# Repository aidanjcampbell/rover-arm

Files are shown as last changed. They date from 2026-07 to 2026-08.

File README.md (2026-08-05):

# Rover-Arm — 4-DOF Rover-Mounted Robotic Arm



**A 3D-printed 4-DOF robotic arm lifting 1000 g at 30 cm reach, 200% of its 0.5 kg design target. 2x 12V DC Motors drive the rover while 4x Feetech servos power the arm, all controlled wirelessly by the ESP32. Designed, built, and tested from scratch.**
---

## Contents
- [Demo](#demo)
- [Overview](#overview)
- [Specifications](#specifications)
- [Key Engineering Decisions](#key-engineering-decisions)
- [Requirements & Verification](#requirements--verification)
- [Build Gallery](#build-gallery)
- [Bill of Materials](#bill-of-materials)
- [CAD & Firmware](#cad--firmware)
- [Development Timeline](#development-timeline)

---

## Demo

| | |
|---|---|
| <video src="https://github.com/user-attachments/assets/dd992043-898a-44c7-ab88-0e8c2c1f0734" width="600" controls></video> | **Payload test** — 1000 g held at 30 cm extension |
| <video src="https://github.com/user-attachments/assets/9e35d78c-9f56-43b6-9285-de8e3515913f" width="600" controls></video> | **Range of motion** — all 4 DOF |
| <video src="https://github.com/user-attachments/assets/c3312b9b-7194-4d76-a24a-d6187b4e6c03" width="600" controls></video> | **Control** — hold-to-jog from phone over onboard WiFi |

---

## Overview

I set out to design a mobile rover-mounted manipulator that lifts 0.5 kg at 30 cm extension, with every structural component printable on a consumer FDM machine. The arm has a 2-axis shoulder (pitch + yaw), single-axis elbow and wrist, and a fork-style end effector, all driven by Feetech serial bus servos on a single half-duplex TTL line.

All structural design, torque budgeting, and component selection are my own work. Firmware was developed with AI assistance (Claude) to move quickly through boilerplate code and debugging, keeping my focus on the mechanical design and system integration. I directed the architecture, integrated it with the hardware, and validated all behavior on the physical build.

---

## Specifications

| Parameter | Value |
|---|---|
| Design payload | 0.5 kg @ 30 cm extension |
| Demonstrated payload | 1.0 kg @ 30 cm |
| Reach | 30 cm |
| Actuators | ST3250 (50 kgf·cm) · 3× ST3215 (30 kgf·cm) |
|Drive Motors| 2x 12V DC 100RPM Motors |
| Controller | ESP32-WROOM-32 (Waveshare General Driver for Robots) |
| Control | Onboard WiFi AP + web UI, hold-to-jog |
| Power | 3S LiPo (11.1 V nominal) |
---

## Key Engineering Decisions

### Switching Control Architecture

Intending to build the entire rover off of the Arduino Uno R3 as my command module, I developed the entire base of the rover using this architecture until I realized that its limited pin numbers were going to cause problems when adding the servo bus. I then made the decision to start from scratch with the ESP32 General Robotics Driver.

Result: The General Robotics Driver integrated the TB6612FNG motor driver, wireless control, and the servo control all into one chip, giving us the number of pins we needed while simplifying electronics with a 47% reduction in internal wires (34 before, 18 after). Here is the full breakdown: [docs/wiringdiagrams.md](docs/wiringdiagrams.md)

### Servo Selection & Safety Factor
As I had no prior experience with robotic arms, I needed a way to break down the problem of servo selection into first principles. To do this, I calculated the torque required for the shoulder joint to lift the arm and a 0.5 KG payload with a safety factor of 2.64 to be 52.9 kg·cm. I also did these calculations for the other joints, which you can see alongside the actual math [here](docs/torquecalculations.md).

Result: I chose the ST3250 servo with 50kg·cm of torque for the shoulder joint. Though it was 5.5% under my calculated safety factor, I reasoned it to be the ideal choice (click the link above for details), and the payload tests affirmed this decision.

### Warren-Truss Forearm Link

The elbow-to-wrist link needed high bending stiffness at a very low mass to allow the actuators to lift the target payload. Rather than a solid printed beam, I used a Warren-truss geometry, which carries load through members in tension/compression rather than bending. The Fusion 360 model is parametric with member angles and lengths driven by expressions of the link length, so the truss regenerates correctly whenever the overall geometry changes without manual rework. See the render beside the integrated truss [here](#build-gallery).

### Base Stability Under Payload

Passing the payload test exposed the next constraint: at full extension, the combined center of gravity shifts forward of the front wheel contact line and the rover tips. Because this is a *mobile* platform, any counterweight added needs to be modular and fixed opposite the arm on the rotating base to offset the tip ping moment about the wheelbase.

Result: I developed and designed a modular counterweight system adaptable to any load the rover might undertake using readily available 2.5 lb. gym plates. The counterweight system scales by roughly 1 plate for every 500g added to the arm, allowing the rover to maintain mobility no matter the load. See more [here](docs/torquecalculations.md).

---

## Requirements & Verification

| # | Requirement | Design response | Verification |
|---|---|---|---|
| R1 | Lift 0.5 kg @ 30 cm | ST3250 shoulder + optimized truss designs + modular counterweight system | ✅ **Passed** — held 0.5 kg at full extension; demonstrated to 1.0 kg |
| R2 | Mobile rover base capable of supporting arm | Differential drive DC motors + custom ball bearing + counterweight | ✅ **Passed** — Rover stays stable while executing rapid maneuvers with an arm payload of 1000g (view the mobility test [here](media/1000g_mobility_test.mp4)) |
| R3 | Untethered operation | Onboard WiFi AP + 3S LiPo | ✅ **Passed** — operated for 20 minutes with arm under variable loads |
| R4 | Consumer-FDM printable | All parts fit P1S bed | ✅ Verified — print inventory in `/cad` |

---

## Build Gallery

<table>
  <tr>
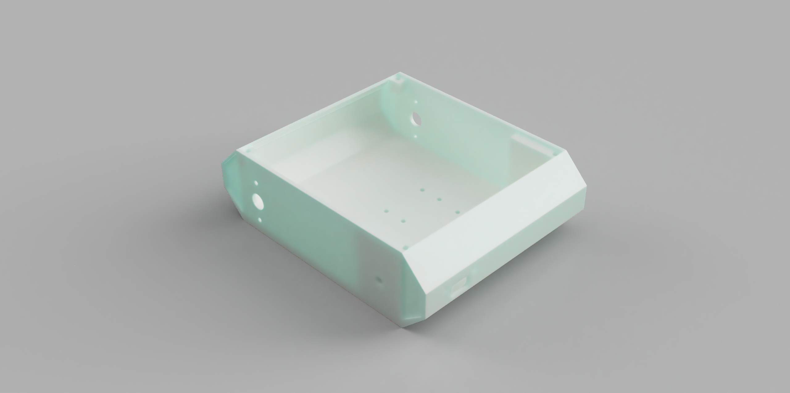
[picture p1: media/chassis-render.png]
    <td></td>
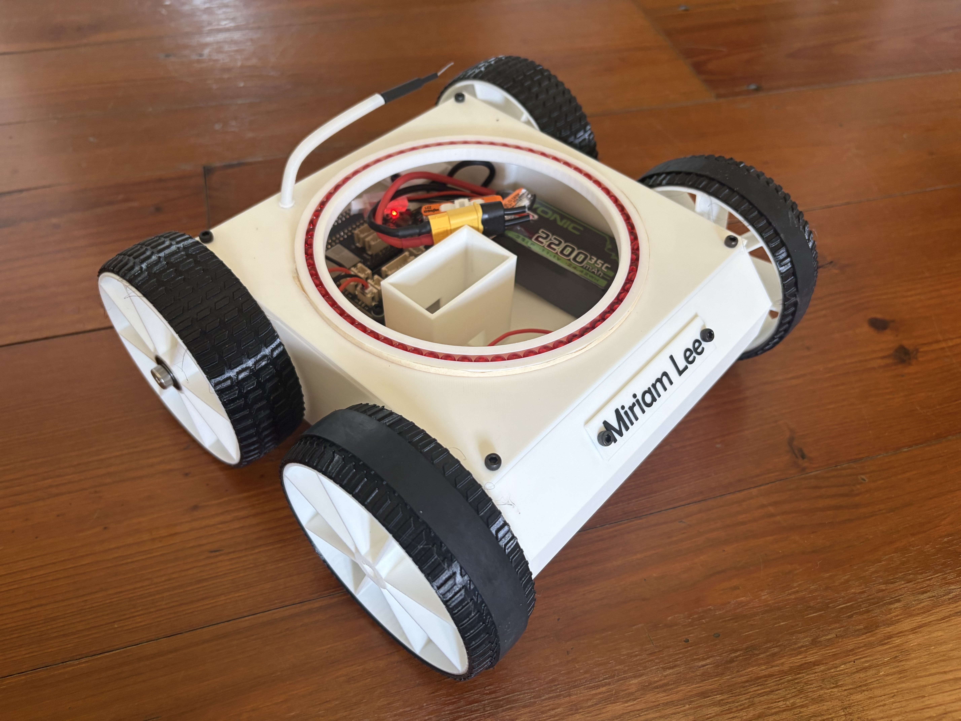
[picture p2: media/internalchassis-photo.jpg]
    <td></td>
  </tr>
  <tr>
    <td align="center"><em>Chassis render — CAD</em></td>
    <td align="center"><em>As built with internal electronics</em></td>
  </tr>
  <tr>
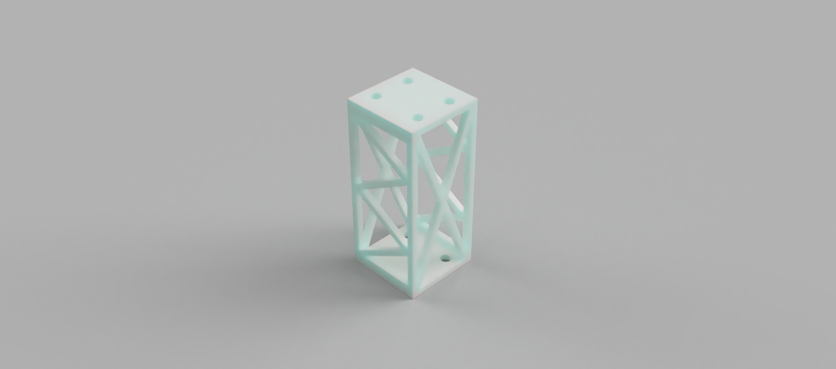
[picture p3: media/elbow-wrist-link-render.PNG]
    <td></td>
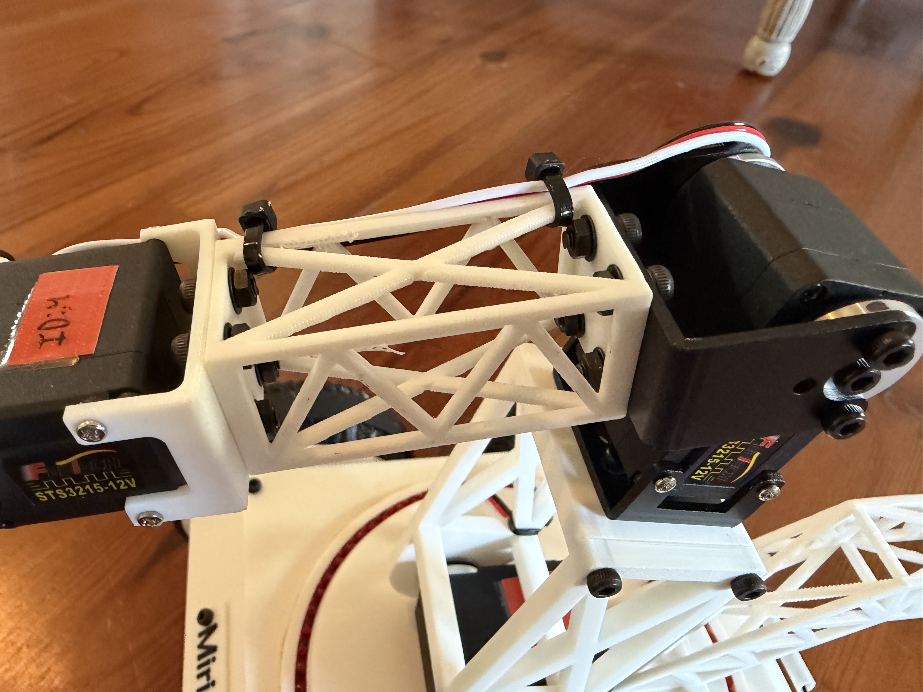
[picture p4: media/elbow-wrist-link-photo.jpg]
    <td></td>
  </tr>
  <tr>
    <td align="center"><em>Elbow-wrist link render — CAD</em></td>
    <td align="center"><em>As built integrated into arm </em></td>
  </tr>
  <tr>
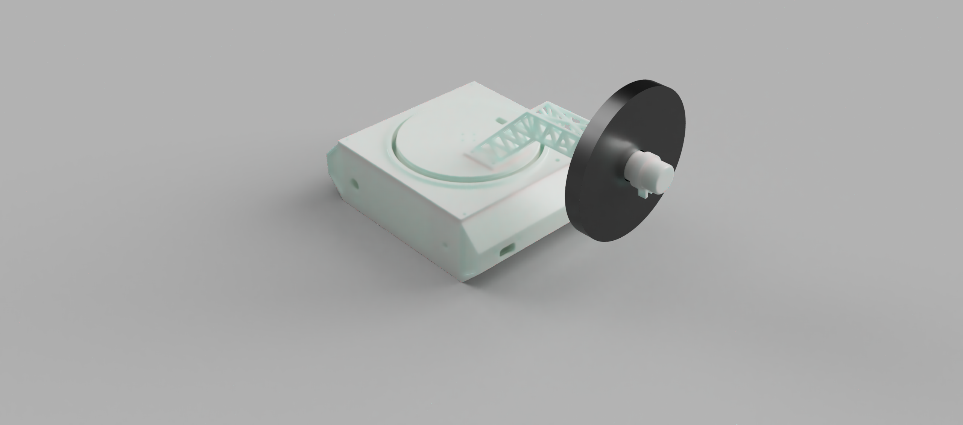
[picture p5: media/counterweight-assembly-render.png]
    <td></td>
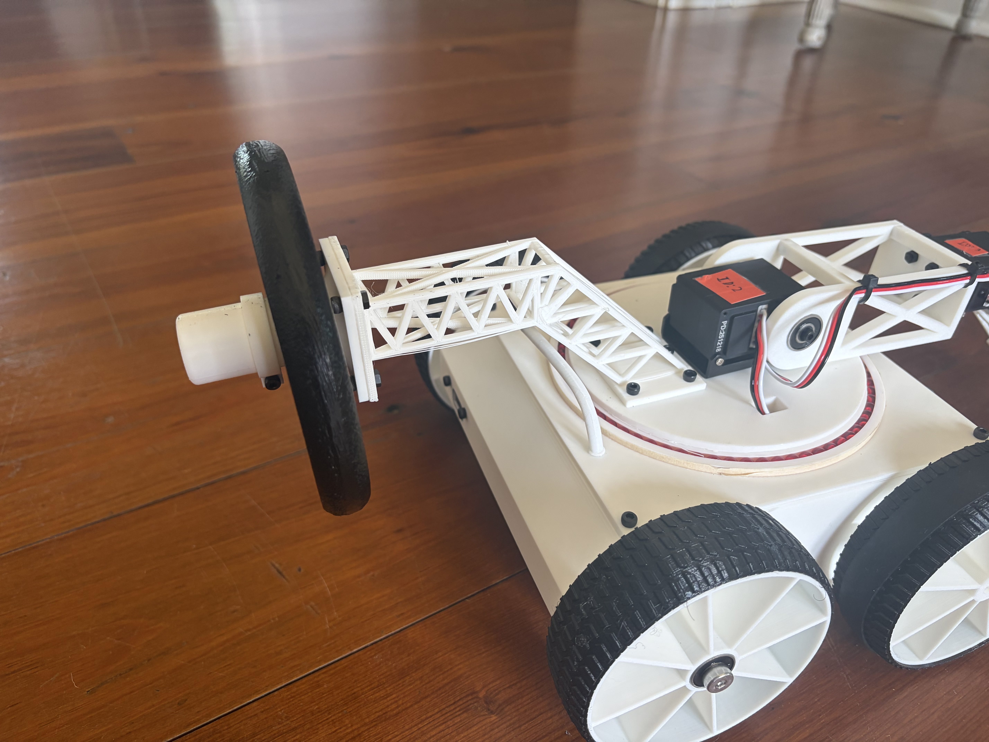
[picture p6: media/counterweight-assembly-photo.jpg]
    <td></td>
  </tr>
  <tr>
    <td align="center"><em>Counterweight assembly render— CAD</em></td>
    <td align="center"><em>As built with 2.5LB(1.1KG) plate </em></td>
  </tr>
  <tr>
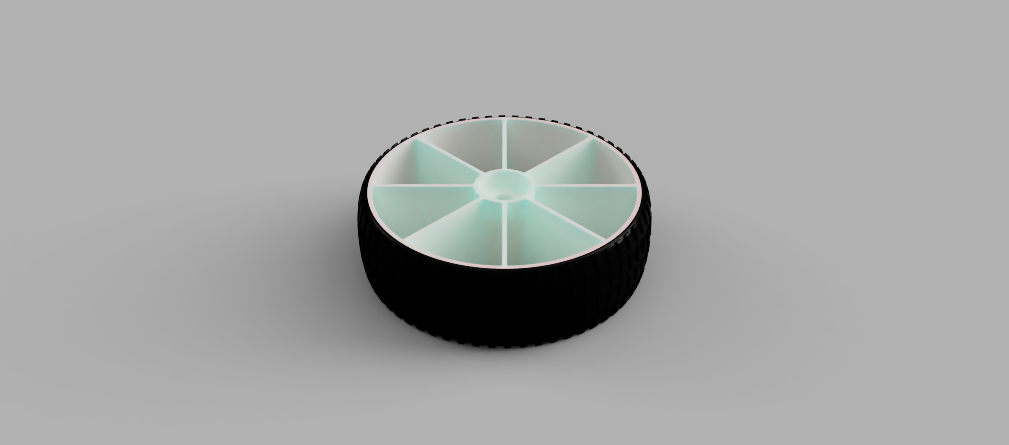
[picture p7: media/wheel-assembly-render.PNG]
    <td></td>
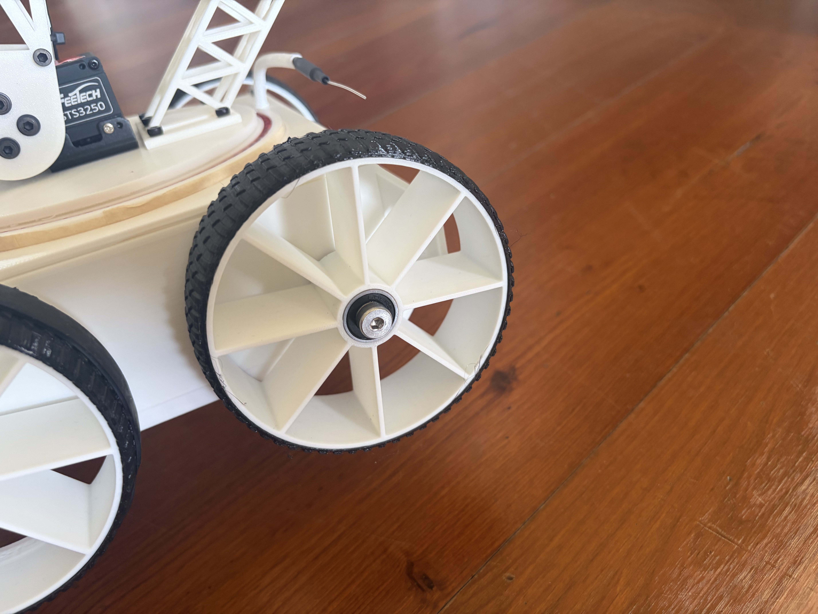
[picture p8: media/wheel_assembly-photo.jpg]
    <td></td>
  </tr>
  <tr>
    <td align="center"><em>Wheel assembly — CAD</em></td>
    <td align="center"><em>As built with non-drive wheel and TPU tire </em></td>
  </tr>
</table>

---

## Bill of Materials

*Key components below. [Full BOM — all hardware, quantities, costs (XLSX)](docs/BOM.xlsx)

| Component | Qty | Spec | Source | Price |
|---|---|---|---|---|
| Feetech ST3250 | 1 | 50 kgf·cm, 12V | [Babsco Supply](https://shop.babsco.com/feetech-sts3250-50kg-heavy-duty-smart-servo) | $64.99 |
| Feetech ST3215 | 3 | 30 kgf·cm, 12V | [DFRobot](https://www.dfrobot.com/product-2962.html) | $19.99 ea |
| Waveshare General Driver for Robots | 1 | ESP32 + TB6612FNG + Servo Bus Control| [Amazon](https://www.amazon.com/Multi-Functional-ESP32-WROOM-32-Bluetooth-Communications-Compatible/dp/B0BZLHYBJL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) | $27.99 |
| Ovonic 3S LiPo | 1 | 11.1V 2200 mAh XT60 | [Amazon](https://www.amazon.com/2200mAh-Connector-Airplane-Quadcopter-Helicopter/dp/B08CZF373Y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) | $16.99 |
| DC 12V 100RPM Motor | 2 | 100RPM 12V | [Amazon](https://www.amazon.com/Greartisan-Electric-Reduction-Centric-Diameter/dp/B072R57C56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) | $14.99 ea |

*Last verified: August 2026. Total: $330.15.*

---

## CAD & Firmware

**CAD** — [STEP files](cad/step/) (any CAD tool) · [STL files](cad/stl/) (print-ready; renders these in an interactive 3D viewer)

**Firmware** — PlatformIO (pioarduino ESP32 fork) + SCServo library. WiFi AP web server with hold-to-jog control, per-joint calibration arrays, build-timestamp version verification at boot.

```bash
pio run -t upload          # build & flash
# connect to "RoverArm" AP → http://192.168.4.1
```

Source and structure in [`/src`](src/).

---

## Development Timeline

- **Getting Started** - Prototyped rover base with intention to use Arduino Uno R3 & HC-05 Bluetooth module for wireless control
- **Architecture Swap** - Swapped Arduino for ESP32 General Robotics Driver after realizing pin limitations (see more [here](docs/wiringdiagrams.md))
- **Actuator sizing** - Torque & inertia calculations + safety-factor decomposition → ST3250 at shoulder pitch (see calculations [here](docs/torquecalculations.md)).
- **Servo bus bring-up** - Isolated a driver-board transceiver fault ([case study](docs/servo-issue.md)); first joint motion on replacement board.
- **Elbow-Wrist Linkage** - Designed/printed lightweight Warren-truss forearm to optimize strength within weight constraints
- **Payload test passed** - 0.5 kg at 30 cm (R1); demonstrated to 1.0 kg.
- **Base stability** — Diagnosed forward tipping resulting from heavy loads lifted by the arm and designed and printed a modular counterweight structure that could be variably loaded depending on arm load
- **Shoulder Joint Failure** - When lifting 1000g, the shoulder-elbow linkage deformed where it mounted to the shoulder servo and caused the arm to fail. Resolved by using a full bolt circle, revised design, and increasing the wall thickness and infill percent on the second iteration print. View the full breakdown [here](docs/structuralfailureanalysis.md).
- **1000g Payload Test** - Arm successfully lifted 1000g (200% of design target) and demonstrated mobile capability while under that load. Due to high heat in the shoulder servo body and several servo shutdowns after extended periods under load, testing will not progress with heavier weight to ensure the rover's continued function.
- **Elbow-Wrist Joint Failure** - During a public demonstration of the rover's capabilities the truss twisted under load and deformed, causing the arm to drop the payload. Resolved by adding two new crossmembers to further close both vertical faces of the truss and resist off-axis forces. View the full analysis [here](docs/structuralfailureanalysis.md).

---

## About

Mechanical engineering student, Georgia Tech. [email](mailto:aidanjcampbell1@gmail.com)

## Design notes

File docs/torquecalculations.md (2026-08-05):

# Torque Calculations — Robotic Arm

Torque sizing and actuator selection for the 4-DOF arm, worked from first principles.

## Requirement

Lift **0.5 kg** at **30 cm** maximum extension.

Configuration: 2-axis shoulder (pitch + yaw), single-axis elbow, single-axis wrist.

## Method
**Total Torque:**
```math
\tau_{\text{tot}} = \tau_s + \tau_I
```
**Static torque about a joint:**
```math
\tau_{\text{s}} = m \cdot L \cdot \cos\theta
```

For a multi-joint system, a joint carries the payload **and** every link and servo outboard of it, each at its own moment arm:

```math
\tau_{\text{joint}} = \sum m \cdot L \cdot \cos\theta
```
Torque is expressed in **kgf·cm**. Because kilogram-force already carries gravitational acceleration, using mass in kg and length in cm yields torque directly. Worst case is $\theta = 0$ (arm horizontal), where the moment arm is longest.

**Inertial Torque about a joint:**

```math
\tau_I = I \cdot \alpha
```
Where
```math
I = \sum mr^2
```
and
```math
\alpha = \frac{4\Delta \theta}{T^2}
```
Because inertia is calculated in $\text{kg}\cdot m^2$, we convert lengths to meters to start. Once we calculate inertial torque, we will convert it from $\text{N}\cdot\text{m}$ to $\text{kgf}\cdot\text{cm}$ using 10.2 $\text{kgf}\cdot\text{cm}$ =1 $\text{N}\cdot\text{m}$ to match our static torque calculations.

---

## Shoulder Pitch Torque

This joint carries the entire arm, so it will have the most torque and will likely be the limiting factor.
Masses are estimated as point masses and lengths as the distances from the center of mass to the shoulder pitch axis.

| Symbol | Quantity | Value |
|---|---|---|
| $m_p$ | Payload mass | 0.5 kg |
| $L_p$ | Payload moment arm| 30 cm |
| $m_{\text{se}}$ | Shoulder-elbow link mass | 0.05 kg |
| $L_{\text{se}}$ | Shoulder-elbow link moment arm| 7.5 cm |
| $m_{\text{es}}$ | Elbow servo mass | 0.055 kg |
| $L_{\text{es}}$ | Elbow servo moment arm | 13 cm |
| $m_{\text{ew}}$ | Elbow-wrist link mass | 0.04 kg |
| $L_{\text{ew}}$ | Elbow-wrist link moment arm | 20.5 cm |
| $m_{\text{ws}}$ | Wrist servo mass | 0.055 kg |
| $L_{\text{ws}}$ | Wrist servo moment arm| 26 cm |
| $m_{\text{f}}$ | Fork mass | 0.03 kg |
| $L_{\text{f}}$ | Fork moment arm| 28 cm |

**Static Torque**

Evaluated at $\theta = 0$, where the arm will experience the maximum load.
Payload contribution:

```math
\tau_p = m_p \cdot L_p \cdot \cos 0^\circ = 0.5 \times 30 \times 1 = 15\ \text{kgf·cm}
```

Link + servo contributions:

```math
\tau_{\text{unloaded arm}} = ((m_{\text{se}} \cdot L_{\text{se}}) + (m_{\text{es}} \cdot L_{\text{es}}) + (m_{\text{ew}} \cdot L_{\text{ew}}) + (m_{\text{ws}} \cdot L_{\text{ws}}) + (m_{\text{f}} \cdot L_{\text{f}})) \cdot \cos 0^\circ = \text{4.18}\ \text{kgf·cm}
```

Total static torque at the shoulder:

```math
\tau_{\text{shoulder}} = \tau_p + \tau_{\text{unloaded arm}} = 19.18 \text{kgf·cm}
```

**Inertial Torque**

Because the acceleration of the arm does not have a requirement, we will set the time to accelerate the arm $90^\circ$ or 1.57 rad to 2 seconds.
```math
\alpha = \frac{4(1.57)}{2^2} = 1.57 \text{rad/s}^2
```
We then calculate the inertia using the data table above.
```math
I = (m_{\text{se}} \cdot (L_{\text{se}})^2) + (m_{\text{es}} \cdot (L_{\text{es}})^2) + (m_{\text{ew}} \cdot (L_{\text{ew}})^2) + (m_{\text{ws}} \cdot (L_{\text{ws}})^2) + (m_{\text{f}} \cdot (L_{\text{f}})^2) + (m_p \cdot (L_p)^2)= 0.0538 \text{kg}\cdot\text{m}^2
```
Then we use the formula for total inertial torque
```math
\tau_I = I \cdot \alpha = (1.57)\text{rad/s}^2 \cdot (0.0538)\text{kg}\cdot\text{m}^2 = 0.08 \text{N}\cdot\text{m} 
```
Converting inertial torque from $\text{N}\cdot\text{m}$ to $\text{kg}\cdot\text{cm}$
```math
0.08 \text{N}\cdot\text{m} \cdot \frac{10.2 \text{kgf}\cdot\text{cm}}{1 \text{N}\cdot\text{m}} = 0.86 \text{kgf}\cdot\text{cm}
```
**Total Shoulder Torque**
```math
\tau_\text{tot} = \tau_s + \tau_I = 19.18 \text{kgf·cm} + 0.86 \text{kgf·cm} = 20.04 \text{kgf·cm}
```
### Safety Factor

| Factor | Value | Rationale |
|---|---|---|
| Continuous vs. stall | 2.0 | Rated stall torque is not usable continuous torque |
| Estimation error | 1.2 | Uncertainty in masses and arm lengths |
| Friction | 1.1 | Joint friction|
| **Stacked** | **≈ 2.64×** | product of the above |

**Required stall torque:**

```math
\tau_\text{req} =  20.04 \text{kgf·cm} \cdot 2.6 = 52.9 \text{kgf·cm}
```

### Selection

| Spec | Value |
|---|---|
| Required stall torque | 52.9 kgf·cm |
| Servo selected | ST3250 |
| Rated stall torque | 50 kgf·cm |
| Margin | 5.8% under |

The ST3250 is under our calculated safety factor, giving us a new safety margin of 2.50. This is a deliberate choice, as we included a large error margin in our estimation and friction safety factor calculations. This choice eats into that safety factor by 5.8%, which is an acceptable tolerance. If the margin below the calculated safety factor was larger, we would have to select another servo. The ST3250 is also the most powerful servo in the ST series, meaning that this is the most torque we can get without changing the architecture again.

---

## Other joints

### Elbow Torque

Because inertial torque is nominal at this joint and at the wrist joint, those calculations will be omitted as our estimation safety factor provides a significant margin for error.

| Symbol | Quantity | Value |
|---|---|---|
| $m_{\text{ew}}$ | Elbow-wrist link mass | 0.04 kg |
| $L_{\text{ew}}$ | Elbow-wrist link moment arm | 7.5 cm |
| $m_{\text{ws}}$ | Wrist servo mass | 0.055 kg |
| $L_{\text{ws}}$ | Wrist servo moment arm | 13 cm |
| $m_{\text{f}}$ | Fork mass | 0.03 kg |
| $L_{\text{f}}$ | Fork moment arm | 15 cm |
| $m_{\text{p}}$ | Payload  mass | 0.5 kg |
| $L_{\text{p}}$ | Payload  moment arm | 17 cm |

```math
\tau_{\text{elbow}} = \sum m \cdot L \cdot \cos 0^\circ = \text{9.9}\ \text{kgf·cm}
```

Required stall torque (× 2.64): **26.14 kgf·cm** → **ST3215** selected, rated 30 kgf·cm.

---

### Wrist Torque

| Symbol | Quantity | Value |
|---|---|---|
| $m_{\text{f}}$ | Fork mass | 0.03 kg |
| $L_{\text{f}}$ | Fork moment arm| 2 cm |
| $m_{\text{p}}$ | Payload mass | 0.5 kg |
| $L_{\text{f}}$ | Payload moment arm | 4 cm |

```math
\tau_{\text{wrist}} = \sum m \cdot L \cdot \cos 0^\circ = \text{2.06}\ \text{kgf·cm}
```

Required stall torque (× 2.6): **5.44 kgf·cm** → **ST3215** selected, rated 30 kgf·cm.

---
## Counterweight torque

The counterweight supplies the **restoring moment** that opposes the arm's tipping moment about the front tipping line. Because it is mounted on the shoulder opposite the arm, it swings through the same arc, so its moment arm is the horizontal distance from the tipping line to the plate's center of mass. Because the tipping line at the front wheels is the most prone to tipping, we will calculate the torque from this point.

Plate spec: one 2.5 lb steel plate = **1.134 kg**.

| Symbol | Quantity | Value |
|---|---|---|
| $m_{cw}$ | Counterweight mass (1 plate) | 1.134 kg |
| $d_{cw}$ | Moment arm (tipping line → CW center of mass) | 23 cm |

### Single plate — 0.5 kg payload

```math
\tau_{cw} = m_{cw} \cdot d_{cw} = 1.134 \times 23 = 26.082\ \text{kgf·cm}
```

This 26.082 kgf·cm is the restoring torque the counterweight directly provides, sizing the arm to lift a 0.5 kg (500 g) payload at full extension. Combined with the chassis restoring moment, it yields the full stability margin recorded below.

### Two plates — 1.0 kg payload

Doubling the payload to 1.0 kg (1000 g) doubles the tipping moment the counterweight must offset. Since the 23 cm moment arm is fixed, the counterweight torque scales linearly with plate mass, so the plate count doubles. Two 2.5 lb plates give 2.267 kg:

```math
\tau_{cw} = m_{cw} \cdot d_{cw} = 2.267 \times 23 = 52.141\ \text{kgf·cm}
```

### Payload-to-counterweight scaling

| Payload | Counterweight | CW mass | Moment arm | Counterweight torque |
|---|---|---|---|---|
| 0.5 kg (500 g) | 1 × 2.5 lb plate | 1.134 kg | 23 cm | 26.082 kgf·cm |
| 1.0 kg (1000 g) | 2 × 2.5 lb plates | 2.267 kg | 23 cm | 52.141 kgf·cm |

With the moment arm held constant at 23 cm, each 2.5 lb plate contributes a fixed **26.082 kgf·cm** of restoring torque. The counterweight requirement therefore scales roughly one plate per 500 g of payload, which makes the modular system an easily extended sizing rule rather than a one-off value.

### Stability check: does the counterweight actually keep the rover upright?

Counterweight torque alone isn't the full picture — it has to be checked against everything trying to tip the rover forward: the arm's own structural weight plus the payload.

| Term | Value |
|---|---|
| $\tau_{arm}$ (arm structure) | 2.784 kgf·cm |
| $\tau_{payload}$ (0.5 kg payload) | 12.000 kgf·cm |
| **$\tau_{tip}$ (total tipping)** | **14.784 kgf·cm** |
| $\tau_{chassis}$ (chassis restoring) | 7.7722 kgf·cm |
| $\tau_{cw}$ (counterweight, 1 plate) | 26.082 kgf·cm |
| **$\tau_{restore}$ (total restoring)** | **33.854 kgf·cm** |

```math
SF = \frac{\tau_{restore}}{\tau_{tip}} = \frac{33.854}{14.784} = 2.29\times
```

Restoring torque exceeds tipping torque by **2.29×** at full extension (θ = 0), the worst-case pose — the rover is stable with meaningful margin, not just barely balanced. And because the system is scalable, we can add another 2.5 lb. plate for every 500g added to the arm load to maintain roughly the same safety factor.

### Dynamic loading margin

The stability check above assumes the arm is stationary. In motion — accelerating a joint or stopping suddenly at a limit — inertial forces briefly add to the tipping side on top of the static gravitational torque. A rigorous treatment would sum $i \alpha r^2$ across every link mass using a measured angular acceleration, but without that hardware data, I used a conservative padding factor instead.

A **1.5× dynamic multiplier** is applied to the static tipping torque to bound worst-case deceleration (e.g. a hard limit-switch stop):

```math
\tau_{tip,dynamic} = 1.5 \times \tau_{tip,static} = 1.5 \times 14.784 = 22.176\ \text{kgf·cm}
```

Checking this against the existing restoring torque:

```math
SF_{dynamic} = \frac{\tau_{restore}}{\tau_{tip,dynamic}} = \frac{33.854}{22.176} = 1.53\times
```

The single-plate counterweight still restores the rover with margin under a padded worst-case dynamic load, though the margin compresses from 2.29× to 1.53× once motion is accounted for.

**Limitations.** The 1.5× factor is an assumed conservative bound, not a measured value as it was not derived from servo acceleration data. A more precise figure would require measuring joint angular acceleration (α) during a commanded move or hard stop, e.g. via high-speed video, and computing $\tau_{dyn} = \sum m \alpha r^2$ across the arm's link masses. However, the counterweight has proven to be effective as seen in this mobility test video with the 1000g payload:
<video src="https://github.com/user-attachments/assets/91ab42fd-473b-42c3-9ab9-9755cc8a7e65" width="800" controls></video>

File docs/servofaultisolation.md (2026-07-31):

# Servo Fault Isolation

## The symptom

I installed a new controller board and wired it to the arm. On power-up, the board's status light came on, but the connected servo would not respond to any command. No movement. No error message. No partial or intermittent behavior. Complete silence.

## Why silence is the hard case

Most bugs give you a thread to pull. A wrong number, an error message, a behavior that's *almost* right. Leads like these allow you to focus in on a specific hardware piece or section of code. But in this situation, I had nothing to initially focus my attention to.

To work around this, I decided to look at the broad picture of the interactions taking place that would make this servo eventually move. By dividing everything into systems, first hardware/software and then further, I was able to isolate areas of possible failure and test them independently.
## The initial signal

While the servo was not functioning, there was a status light visible inside the servo housing. This led me to believe that the servo was at least receiving power and possibly commands, focusing my attention towards software first.

## Mapping the possibilities

Before touching anything, I listed every layer that could produce total silence:

- my control software
- the communication settings (servo ID, wiring orientation, device addresses)
- the physical wiring
- a defective motor
- a defect on the board itself

Here is my full problem diagnosis tree:

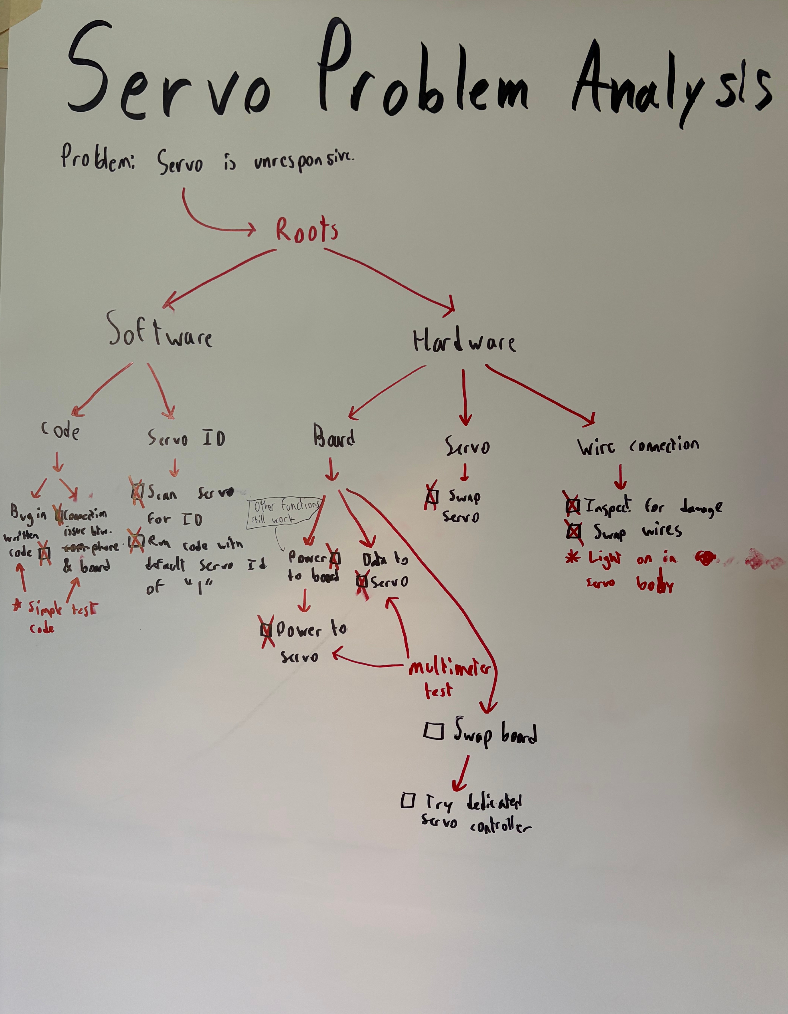
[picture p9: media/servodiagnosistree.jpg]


To efficiently work through this tree and eliminate as many potential problems as possible while following the hint the status light gave me, I decided to start on the software side of the tree. In doing this, I was able to eliminate any potential software bugs before I tried replacing hardware, which delays iteration speed with shipping time and costs more money. 

## Shrinking the problem

The full firmware ran a web interface, motor control, and a wireless connection layered on top of the motor communication. Any of those could have been interfering. So I set all of it aside and wrote a bare test program that did nothing but talk to the motors.

This was the core move: hold everything constant, remove one thing. If the motors worked in the stripped-down program, the fault lived somewhere in the rest of the system. If they still didn't, I'd eliminated an entire category of suspects in a single step.

With that minimal test I confirmed, one check at a time: the board had power, the software was the correct version, the wiring matched the manufacturer's own reference exactly, every valid orientation of the communication wires was tried, and I scanned the full range of possible servo IDs at every possible communication speed. Each check closed off a branch. None produced a response.

## The remaining three

That left three possibilities I could not tell apart from software:

1. a defective motor
2. a defect on the board
3. a defective wire

These three were physically separable, and I could state in advance what each test would prove:

- **Another servo on the same board.** If it works, the first servo was the problem. If it doesn't, the servo isn't the issue.
- **Another wire with the same setup.** If it works, the first wire was the problem. If it doesn't, that leaves only the board on my decision tree.
- **The same setup on a second board.** If it works, the original board was defective. If it doesn't, the fault is somewhere I haven't looked yet or with the design of the board itself, testable with a bare-bones servo controller.

Stating the expected outcome *before* running the test is what separates a diagnosis from swapping parts and hoping something changes.

## Resolution

I first used a multimeter to test if the board was supplying sufficient power to the servo and if the data line was working, both of which were. As all other functions on the board seemed to work properly, I decided to move on to test the other two possibilities.

But after testing both the new servo and new wire (the servo and wire to be used on the elbow joint), they both produced no result, eliminating them from the tree.

I then moved the identical code and hardware setup onto a replacement board. The motors responded immediately.

Nothing in my software, wiring, or configuration had changed — so the one thing that *did* change was the fault. The original board had a defective communication circuit: either a factory defect or a component I damaged during the development process, either of which would have gone unnoticed as all other functions worked.

## Why the diagnosis mattered

The fix was trivial: swap a board. That's worth being honest about — the value here was never the fix.

The days went into *earning* the conclusion. A hardware defect is the one root cause that can't be measured directly; no test ever reads "board faulty." It can only be reached by eliminating everything under my control first. Blaming the hardware before that point is a guess; blaming it after is a diagnosis. The discipline was refusing the comfortable assumption that the new part was fine until I had concretely proven where the fault was not.

## Principles

1. When a system is completely silent, there's no signal to follow — shrink the space instead: hold everything constant, remove one variable at a time, until the cause is cornered.
2. A hardware fault is only a credible conclusion after the controllable parts are exhausted, never before. Reaching for it early feels like progress and usually isn't.

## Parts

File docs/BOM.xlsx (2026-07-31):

Bill of Materials
Rover Project | Aidan Campbell |  |  | 2026-07-17
Item | Quantity | Unit Price($) | Total Price($) | Source | Purchase Link | Notes
Feetech ST3215 12V | 3 | $19.99 | $59.97 | DFRobot | DFRobot ST3215 (https://www.dfrobot.com/product-2962.html)
Feetech ST3250 12V | 1 | $64.99 | $64.99 | Babsco | Babsco ST3250 (https://shop.babsco.com/feetech-sts3250-50kg-heavy-duty-smart-servo)
ST32 Series Servo Horns | 4 | N/A | N/A | N/A | N/A | Included with servo purchases
ST32 Series Servo Bushings | 2 | N/A | N/A | N/A | N/A | Included with servo purchases
ST32 Series Screws | 12 | N/A | N/A | N/A | N/A | Included with servo purchases
ST32 Series Servo Wires | 4 | N/A | N/A | N/A | N/A | Included with servo purchases
Waveshare General Robotics Driver | 1 | $27.99 | $27.99 | Amazon | Waveshare Board (https://www.amazon.com/Multi-Functional-ESP32-WROOM-32-Bluetooth-Communications-Compatible/dp/B0BZLHYBJL)
M3 15mm Standoffs | 4 | N/A | $5.69 | Amazon | Lagogia M3 Standoffs (https://www.amazon.com/Female-Standoff-Quadcopter-Computer-Circuit/dp/B0BPCKHLT5)
12V DC Motor 100RPM | 2 | $14.99 | $29.98 | Amazon | 12V DC Motor (https://www.amazon.com/Greartisan-Electric-Reduction-Centric-Diameter/dp/B072R57C56)
11.1V 2200 mAh LiPo Battery | 1 | $16.99 | $16.99 | Amazon | Ovonic 11.1V LiPo (https://www.amazon.com/2200mAh-Connector-Airplane-Quadcopter-Helicopter/dp/B08CZF373Y)
XT60 Female Connector | 1 | N/A | $4.89 | Amazon | Ledavillage XT60 (https://www.amazon.com/Ledvillage-Female-Connector-Battery-Included/dp/B0DB1V6FFY)
22 AWG Assorted Stranded Wires | 1 | N/A | $9.00 | Amazon | Fermerry wire kit (https://www.amazon.com/Fermerry-Stranded-Electric-Tinned-Copper/dp/B089CQ2N69)
22 AWG x 2.8mm Female Spade Connector | 4 | N/A | $5.99 | Amazon | Baomian Connector Kit (https://www.amazon.com/Baomain-Insulated-Connector-Electrical-Terminal/dp/B01962MW2G)
Heat Shrink Tubing 2.5x45 mm | 10 | N/A | $4.99 | Amazon | Rindion Heat Shrink (https://www.amazon.com/Rindion-127PCS-Heat-Shrink-Tubing/dp/B0DYSV5Z9B) | Any diameter 2-3mm and length 20-50mm could substitute
M5 30mm Shoulder Screw | 2 | N/A | $7.99 | Amazon | UXCell M5 Screws (https://www.amazon.com/uxcell-Stainless-Socket-Shoulder-Length/dp/B077GYB893)
606-2RS 6x17x6mm Ball Bearing | 5 | N/A | $6.49 | Amazon | UXCell 606-2RS
2.5 x 200mm Zip Ties | 4 | N/A | $3.99 | Amazon | HoAoOo Cable Ties (https://www.amazon.com/Nylon-Cable-inches-Heavy-2-5mm/dp/B0GR52PRHF)
JST-PH 2.0 Connector | 2 | N/A | $5.99 | Amazon | Twisina JST PH (https://www.amazon.com/Connector-Connectors-Female-Silicone-Cables/dp/B0GWYR7CQ2)
JST-XH 2.54 Connector | 1 | N/A | $6.99 | Amazon | ZSDZFYLLK JST-XH (https://www.amazon.com/JST-XH-2-54mm-Connector-Silicone-Cables/dp/B0D6KSMK1Q)
M3x6mm socket cap screws | 31 | N/A | $9.99 | Amazon | Fgruh M3 Kit (https://www.amazon.com/Fgruh-750PCS-Assortment-Washers-Assorted/dp/B0FGV5FCBN) | M3 750 piece kit. Only 1 required for all M3 screws needed.
M3x8mm socket cap screws | 27 | N/A |  | Amazon | Fgruh M3 Kit (https://www.amazon.com/Fgruh-750PCS-Assortment-Washers-Assorted/dp/B0FGV5FCBN) | Included in Fgruh M3 Kit
M3x12mm socket cap screws | 1 | N/A |  | Amazon | Fgruh M3 Kit | Included in Fgruh M3 Kit
M3x16mm socket cap screws | 4 | N/A |  | Amazon | Fgruh M3 Kit | Included in Fgruh M3 Kit
M3 Nut | 25 | N/A |  | Amazon | Fgruh M3 Kit | Included in Fgruh M3 Kit
M5x8mm Heat-Set Insert | 2 | N/A | $8.99 | Amazon | FFVRVSS Heat Inserts (https://www.amazon.com/M2-M2-5-M3-Threaded-Inserts/dp/B0FH4JQ3VB) | 320+6pcs M2-M5 set. Only 1 required for all heat set inserts.
M3x5mm Insert | 23 | N/A |  | Amazon | FFVRVSS Heat Inserts (https://www.amazon.com/M2-M2-5-M3-Threaded-Inserts/dp/B0FH4JQ3VB) | Included in FFVRVSS Heat Insert Kit
PLA Filament 1.75mm white | ~1kg | $15.29 | $15.29 | Amazon | SUNLU PLA Filament (https://www.amazon.com/Printer-Filament-SUNLU-Dimensional-Accuracy/dp/B07ZNHF46J)
90a TPU Filament 1.75mm black | 240g | $24.99 | $24.99 | Amazon | SUNLU TPU Filament (https://www.amazon.com/SUNLU-TPU-Filament-1-75mm-Flexible/dp/B0FB95ZMCM)
Size #85 Rubber Bands | 2 | N/A | $8.96 | Amazon | HAIDIBAO Rubber Bands (https://www.amazon.com/HAIDIBAO-Rubber-Assorted-Elastic-Survival-Tactical/dp/B0DNFGJYNZ) | For enhanced tire grip if TPU lacks traction on slick surfaces
 |  | Total Price: | $330.15

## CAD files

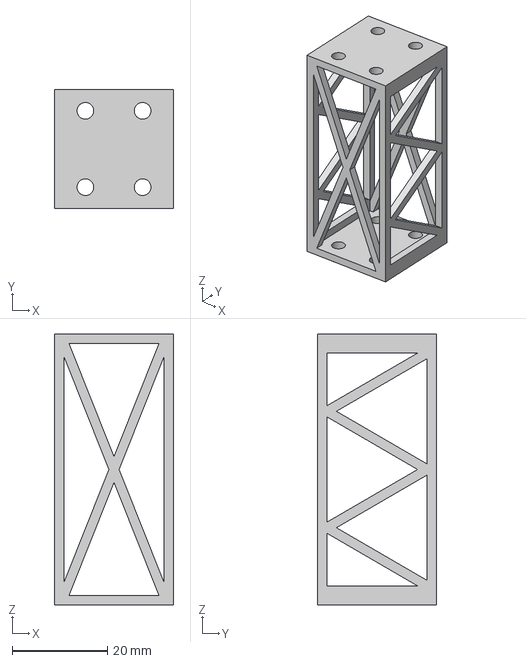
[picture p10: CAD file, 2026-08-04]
cad/step/elbow-wrist-link.step
25.0 x 25.0 x 56.8 mm

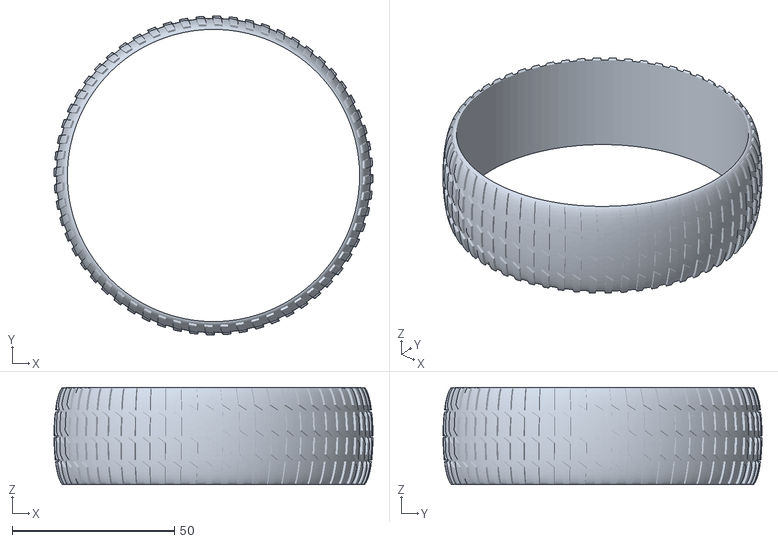
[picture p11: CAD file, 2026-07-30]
cad/stl/tire.stl
98.2 x 98.2 x 30.0

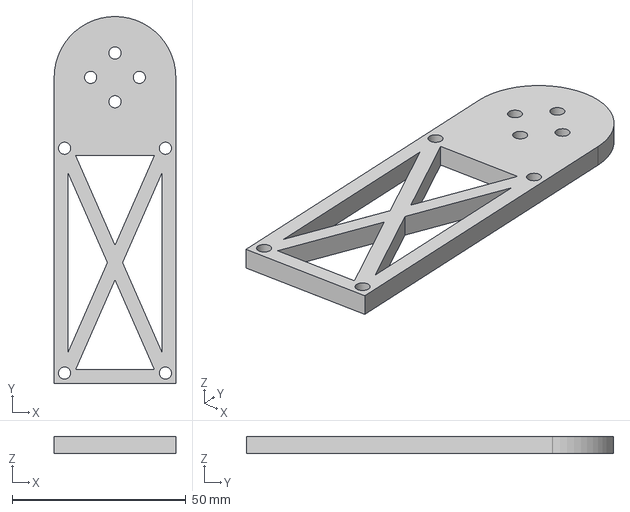
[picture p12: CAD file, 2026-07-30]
cad/step/shoulder-elbow-servo-link.step
35.0 x 105.5 x 5.00 mm

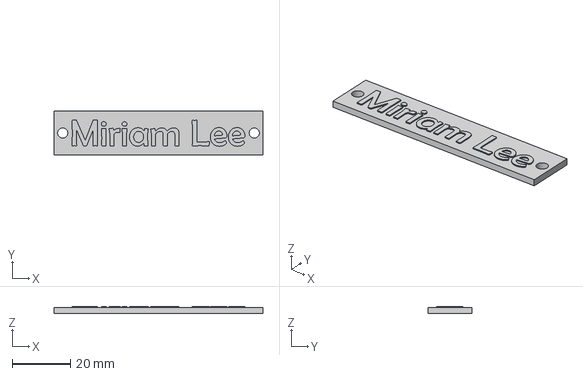
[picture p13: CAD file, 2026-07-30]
cad/step/nameplate.step
72.0 x 15.0 x 2.32 mm

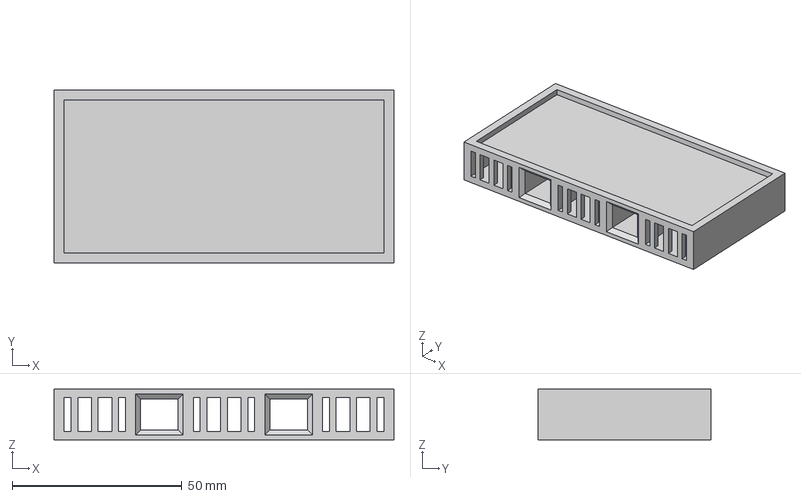
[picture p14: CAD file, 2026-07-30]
cad/step/pallet.step
100.0 x 51.0 x 15.0 mm

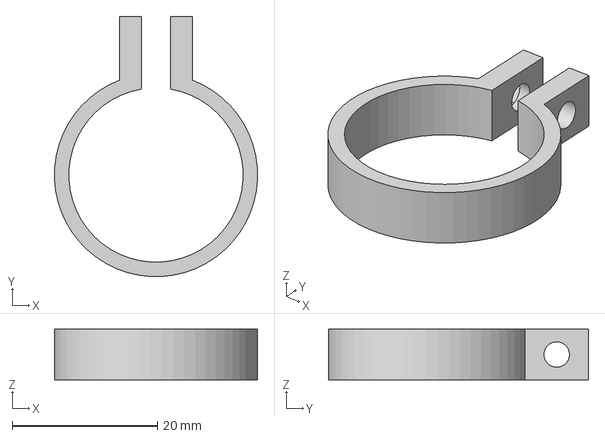
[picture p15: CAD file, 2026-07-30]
cad/step/counterweight-clamp.step
28.0 x 35.8 x 7.00 mm

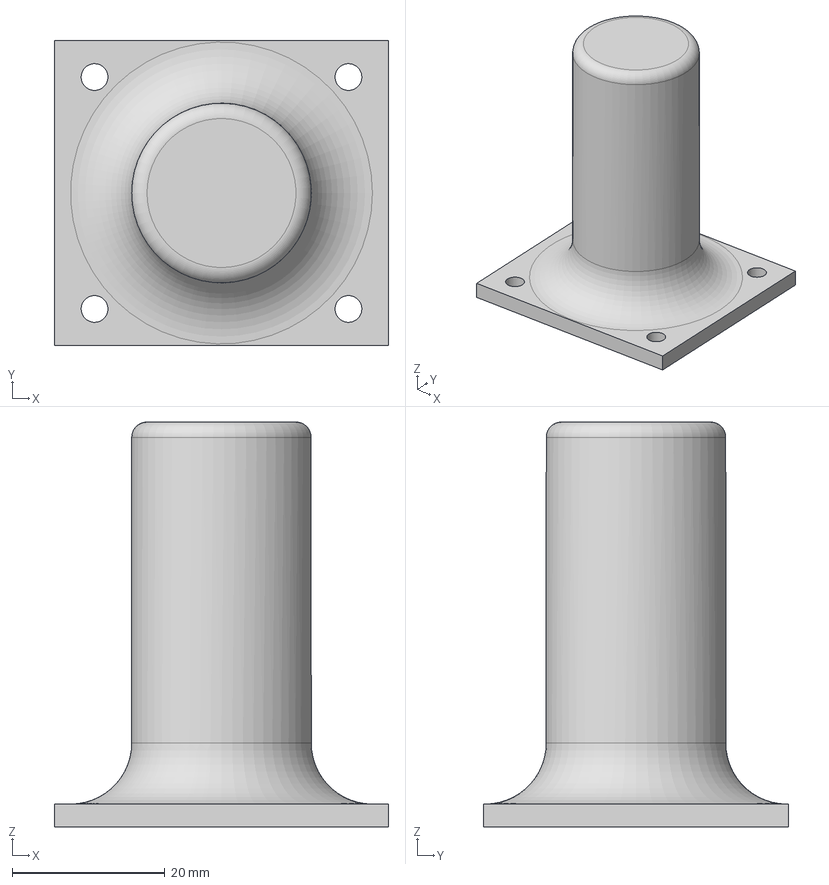
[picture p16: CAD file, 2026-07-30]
cad/step/counterweight-holder.step
43.8 x 40.0 x 53.0 mm

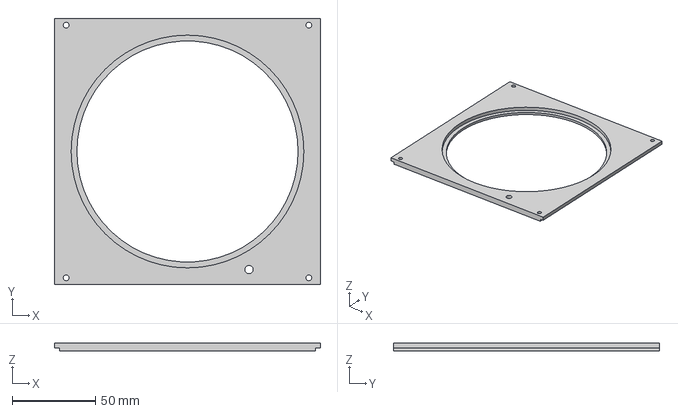
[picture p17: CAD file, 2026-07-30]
cad/step/top-plate.step
160.0 x 160.0 x 5.00 mm

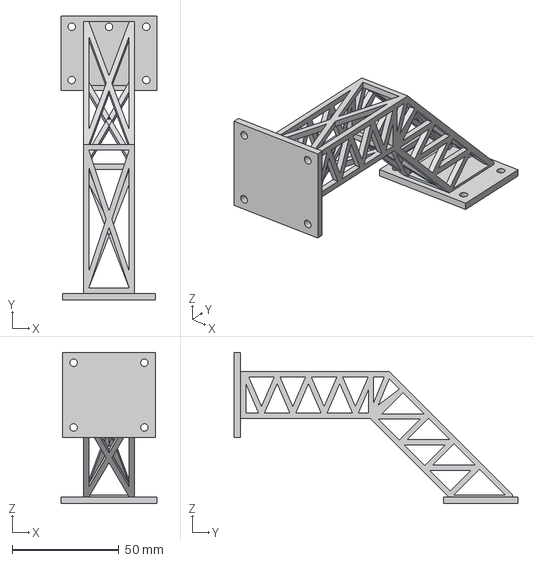
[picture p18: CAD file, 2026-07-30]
cad/step/counterweight-truss.step
45.0 x 133.1 x 70.8 mm

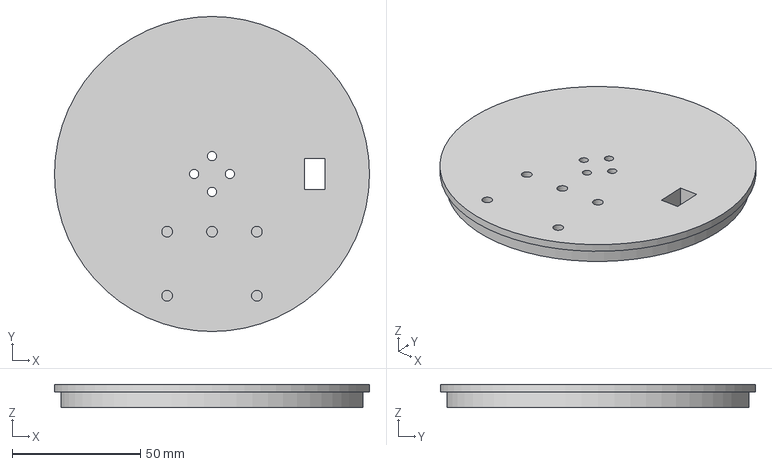
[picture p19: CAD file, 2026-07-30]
cad/step/yaw-plate.step
122.9 x 122.9 x 9.00 mm

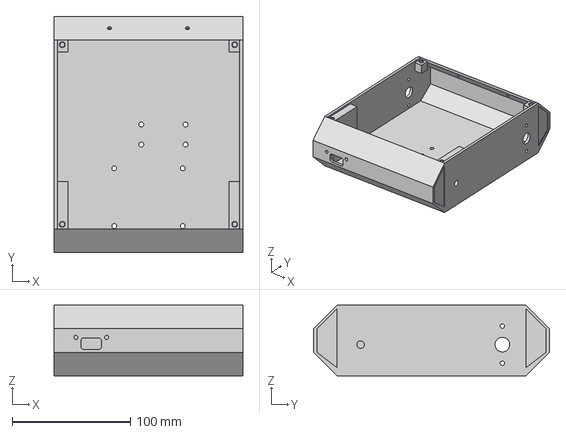
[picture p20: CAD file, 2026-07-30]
cad/step/chassis.step
160.0 x 200.0 x 60.0 mm

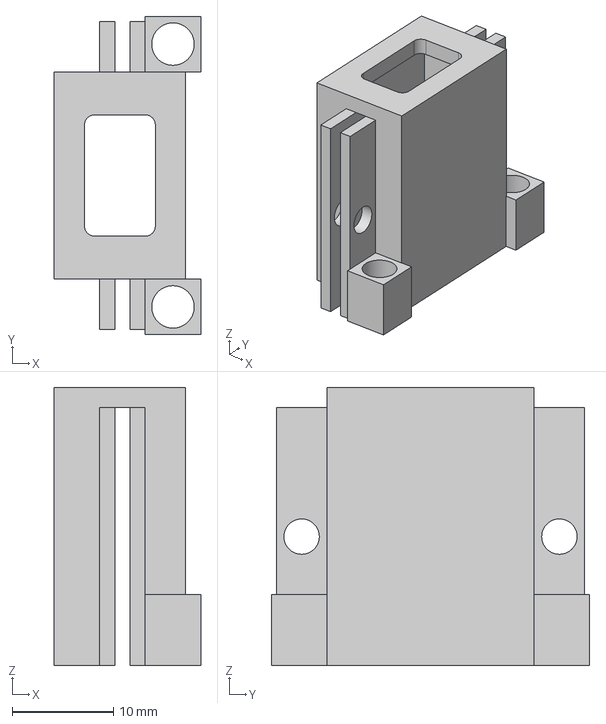
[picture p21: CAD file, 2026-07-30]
cad/step/USB-holder.step
14.5 x 31.5 x 27.5 mm

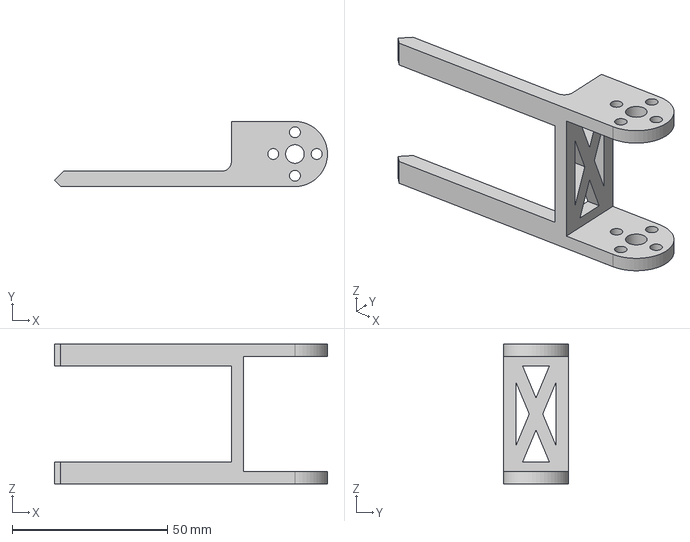
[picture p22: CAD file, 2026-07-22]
cad/step/fork-end-effector.step
88.0 x 21.0 x 45.0 mm

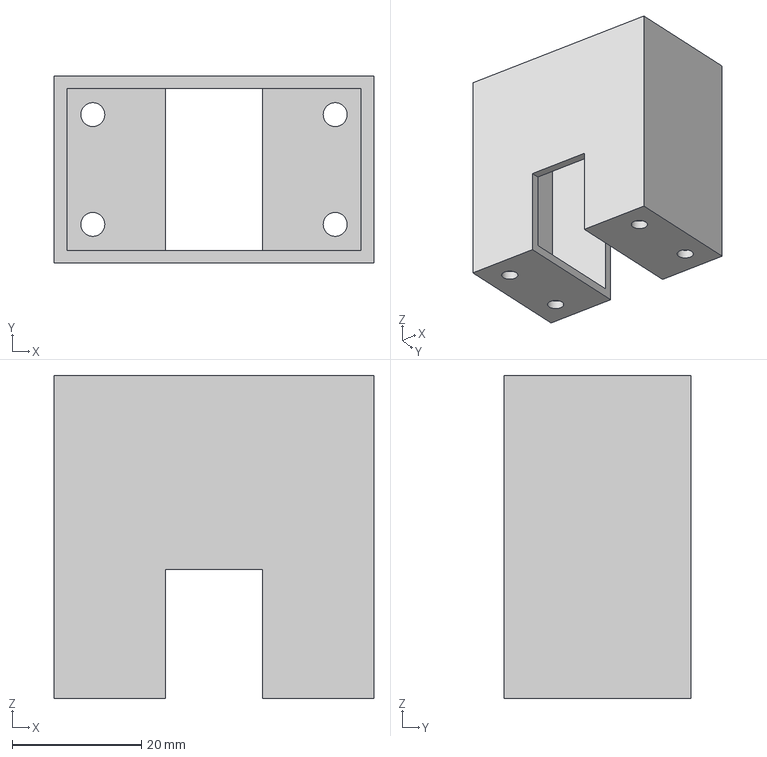
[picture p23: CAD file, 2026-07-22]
cad/step/servo-box.step
49.5 x 29.0 x 50.0 mm

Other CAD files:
cad/step/shoulder-bearing-spacer.step
cad/step/servo-bracket.step
cad/step/antenna-structure.step
cad/step/non-drive-wheel.step
cad/step/drive-wheel.step
cad/step/shoulder-elbow-link.step
cad/step/shoulder-yaw-bearing.step
cad/step/wheel-spacer.step
cad/stl/USB-holder.stl
cad/stl/antenna-structure.stl
cad/stl/chassis.stl
cad/stl/counterweight-clamp.stl
cad/stl/counterweight-holder.stl
cad/stl/counterweight-truss.stl
cad/stl/drive-wheel.stl
cad/stl/elbow-wrist-link.stl
cad/stl/fork-end-effector.stl
cad/stl/nameplate.stl
cad/stl/non-drive-wheel.stl
cad/stl/pallet.stl
cad/stl/servo-box.stl
cad/stl/servo-bracket.stl
cad/stl/shoulder-bearing-spacer.stl
cad/stl/shoulder-elbow-link.stl
cad/stl/shoulder-elbow-servo-link.stl
cad/stl/shoulder-yaw-bearing.stl
cad/stl/top-plate.stl
cad/stl/wheel-spacer.stl
cad/stl/yaw-plate.stl

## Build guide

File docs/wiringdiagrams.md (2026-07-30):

# Wiring & Control Architecture
 
The control electronics were migrated from an initial **Arduino Uno** prototype to the **Waveshare General Driver for Robots 
(ESP32-WROOM-32)**. This document shows both wiring architectures and explains the reasoning behind the switch.

## Why the architecture changed

The Uno prototype hit a hard limit with pin space, a crucial component for the platform.
The decisive factor was the **serial bus servos**: the Feetech actuators run on a half-duplex serial bus at 1,000,000 baud, 
which needs a *dedicated* hardware UART. The Uno has a single UART shared with USB programming/debug, 
so the servo bus and the debug link contend for the same peripheral, meaning a dedicated servo controller wpould have to be added into the architecture. Add in the motor driver and HC-05 Bluetooth module along with the dedicated servo controller, and the Arduino does not have enough pins to support that architecture, not to mention its complexity.

| Requirement | Arduino Uno | Waveshare (ESP32) |
|---|---|---|
| Serial bus servos @ 1 Mbaud | Single UART, shared with USB — no dedicated bus | Multiple hardware UARTs; dedicated `Serial1` on GPIO18/19 |
| Wireless control | None, requires HC-05 bluetooth module | Onboard Wi-Fi; hosts the `RoverArm` AP + web UI at 192.168.4.1 |
| Motor driving | Requires separate motor driver | Integrated TB6612FNG driver |

The switch consolidated the electronics onto a single robotics-purpose board and freed a dedicated UART for the servo bus, which later proved important when diagnosing a servo bus power issue (see [`servofaultisolation.md`](servofaultisolation.md)).

## Diagram 1 — Original architecture (Arduino Uno)

Original wiring: Arduino Uno prototype architecture

The initial prototype: This setup worked well in the beginning as I was familiar with using the Arduino Uno R3, but quickly reached its limits once I needed to add the servo bus and control.

## Diagram 2 — Current architecture (Waveshare ESP32)

Current wiring: Waveshare General Driver (ESP32) architecture

The current system: power distribution from the 3S LiPo, the ESP32 hosting the Wi-Fi AP and web interface, the integrated TB6612FNG driving the drive motors, and the Feetech servo bus running on `Serial1` (GPIO18 `S_RXD` / GPIO19 `S_TXD`), half-duplex at 1,000,000 baud.

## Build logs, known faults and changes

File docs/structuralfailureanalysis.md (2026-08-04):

# Structural Failure Analysis: Shoulder Joint and Forearm Truss at 1000g
 
While testing the rover at a 1000g payload — 200% of its 0.5 kg design target — I encountered two separate structural failures on the arm. This is a record of both: what failed, why it failed, and what I changed to fix the root cause.
 
The two are worth reading together because they failed for different reasons. The first was a build failure--the design was sound, but I did not assemble the part correctly. The second was a design failure--the part was built as intended, but my model of how it would be loaded was incomplete. One taught me to build and assemble to spec; the other taught me to question my load assumptions.
 
---
 
## Failure #1: Shoulder–Elbow Joint
 
<video src="https://github.com/user-attachments/assets/7db130d6-03f4-4d7d-aa30-b8c59f9642bd" width="600" controls></video>
*The joint giving way during the first 1000g payload test.*
 
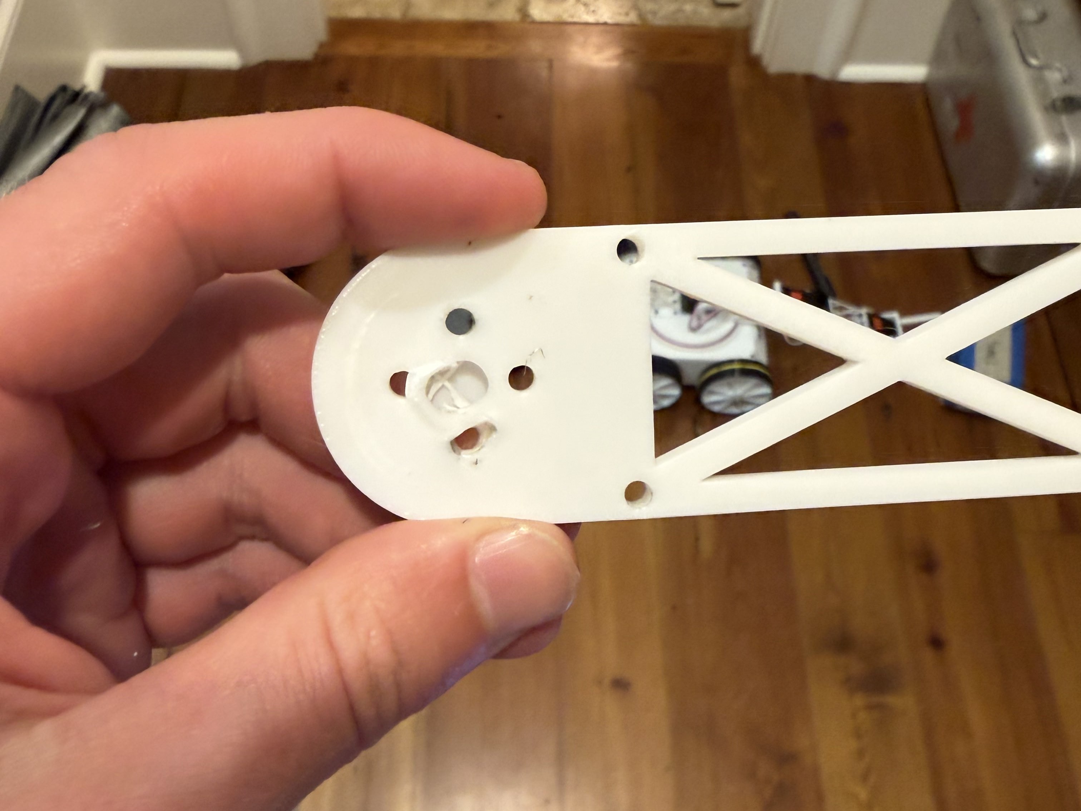
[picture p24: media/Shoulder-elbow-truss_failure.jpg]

*The mounting plate after failure with the deformed screw holes.*
 
This failure appeared the first time I tested the 1000 g payload. The mounting plate on the shoulder–elbow link — the plate that bolts to the shoulder servo horn and carries the entire arm — deformed and pulled apart at the screw holes under the accumulated stress of repeated payload tests.
 
**Root causes:**
 
- **Prototype print settings.** The link holding up the whole arm had been printed at 2 walls and 15% infill — settings that are fine for prototyping but not for carrying large loads. With too few perimeters around the screw bosses, the holes had little material to resist the load and began to deform and elongate until they tore through.
- **Too few fasteners.** I had used two fasteners at the joint instead of the four the design called for, because two allowed faster disassembly during iteration. That forced the entire arm load through two screws, which was inadequate under heavy payload.
- **Hand-drilled center hole.** The center hole that lets the plate sit flush on the servo horn had been drilled with a power tool after printing rather than modeled into the part. This left a weak spot at the center of the plate and disrupted the surrounding material, which contributed to the screw holes deforming and failing.

**Fixes, each addressing a specific cause:**
 
- **Print settings → 3 walls, 25% infill.** The extra perimeters put more solid material around the screw bosses, where the load actually transfers, giving the holes far more resistance to deformation.
- **Fasteners → four, with washers and preload.** Going back to the full four-fastener pattern with washers spreads the load across the joint instead of concentrating it on two screws. I also preloaded the bolts more firmly: clamping the plate against the servo horn lets the joint carry load through friction across the whole mating face, taking stress off the screw holes themselves rather than relying on the screws in shear alone.
- **Center hole → designed into the print.** Modeling the hole into the part kept the surrounding material continuous and the plate's structural integrity intact.
**Result:** These changes fixed the joint. The reprinted link has passed several further 1000g tests without deformation.
 
---
 
## Failure #2: Elbow–Wrist Forearm Truss

*The single-crossmember truss after it twisted under an off-axis load.*
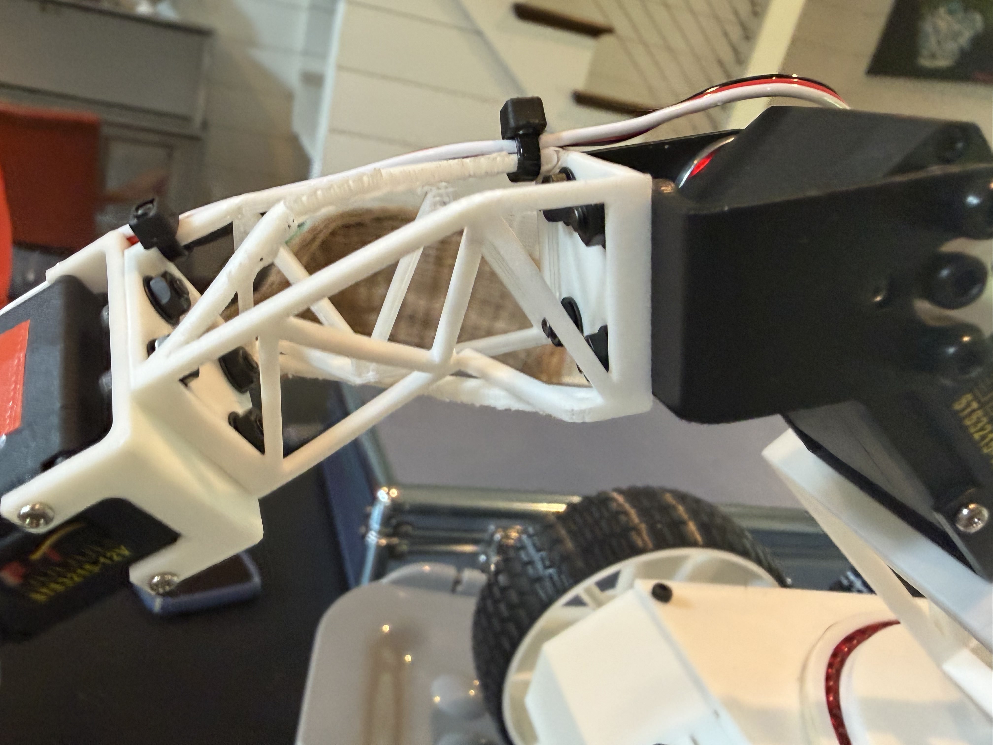
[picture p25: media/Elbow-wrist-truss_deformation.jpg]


This failure appeared during a demonstration of the rover lifting 1000 g. Mid-lift, the elbow–wrist link twisted along its length and deformed, and the arm failed.
 
**Root cause:**
 
I had designed the elbow–wrist link to be highly weight-optimized — strong where it needed to be, light everywhere else. Working from that mindset, I gave the top and bottom faces of the truss only a single crossmember each, because I expected the link to carry load only vertically, down the side faces. That reasoning held for a purely vertical load. But when the rover lifts a payload that isn't perfectly balanced, or when the arm accelerates in the yaw direction, the load comes off the vertical axis and tries to twist the link along its length. With only one crossmember per face, the top and bottom behaved as an **open section**, which has very little torsional stiffness — so under that off-axis load, the truss twisted rather than holding its shape.
 
**Fix:**
 
<!-- MEDIA: render or photo of the two-crossmember redesign -->

 
I redesigned the truss with the same weight-optimization mindset but a corrected understanding of how it would actually be loaded. The change was to run **two crossmembers per face instead of one**. Tying the top and bottom faces together this way further closes the section, better approximating a true closed section. This design resists torsion far better than a fully open one while keeping the lightweight advantage of a truss over a solid beam. The realization behind the fix wasn't "add more material"; it was that I had modeled only the in-plane bending load and missed the torsional load path.
 
**Result:** the redesigned truss has passed every 1000g test since, and it holds its shape far better when the arm is loaded during dynamic movement.
 
---
 
## Takeaway
 
Both failures resulted from deliberately testing past the design requirement to reveal the real limits of the build. The shoulder joint failed because the as-built part drifted from its design under the pressure of rapid iteration; the fix was discipline in fabrication. The forearm truss failed because the design itself was built on an incomplete load model; the fix was a better understanding of the loads. Together they moved the arm from meeting its 0.5 kg target to holding 1000g repeatably.

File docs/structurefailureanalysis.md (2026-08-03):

# Structural Failure Analysis: Shoulder Joint and Forearm Truss at 1000 g
 
While testing the rover at a 1000 g payload — 200% of its 0.5 kg design target — I encountered two separate structural failures that took the arm out of service. This is a record of both: what failed, why it failed, and what I changed to fix the root cause.
 
The two are worth reading together because they failed for different reasons. The first was a build failure — the design was sound, but the as-built part didn't match it. The second was a design failure — the part was built as intended, but my model of how it would be loaded was incomplete. One taught me to build to spec; the other taught me to question my load assumptions.
 
---
 
## Failure #1: Shoulder–Elbow Joint
 
<!-- MEDIA: failure video — drag-and-drop the 1000 g joint-failure clip here on GitHub, or replace the line below -->
Shoulder–elbow joint failing during the first 1000 g test
*The joint giving way during the first 1000 g payload test.*
 
<!-- MEDIA: photo of the deformed part -->
Deformed shoulder–elbow mounting plate
*The mounting plate after failure — the screw holes deformed and tore out under load.*
 
This failure appeared the first time I tested the 1000 g payload. The mounting plate on the shoulder–elbow link — the plate that bolts to the shoulder servo horn and carries the entire arm — deformed and pulled apart at the screw holes under the accumulated stress of repeated payload tests.
 
**Root causes:**
 
- **Prototype print settings.** The link holding up the whole arm had been printed at 2 walls and 15% infill — settings that are fine for prototyping but not for carrying large loads. With too few perimeters around the screw bosses, the holes had little material to resist the load and began to deform and elongate until they tore through.
- **Too few fasteners.** I had used two fasteners at the joint instead of the four the design called for, because two allowed faster disassembly during iteration. That forced the entire arm load through two screws, which was inadequate under heavy payload.
- **Hand-drilled center hole.** The center hole that lets the plate sit flush on the servo horn had been drilled with a power tool after printing rather than modeled into the part. This left a weak spot at the center of the plate and disrupted the surrounding material, which contributed to the screw holes deforming and failing.

**Fixes, each addressing a specific cause:**
 
- **Print settings → 3 walls, 25% infill.** The extra perimeters put more solid material around the screw bosses, where the load actually transfers, giving the holes far more resistance to deformation.
- **Fasteners → four, with washers and preload.** Going back to the full four-fastener pattern with washers spreads the load across the joint instead of concentrating it on two screws. I also preloaded the bolts more firmly: clamping the plate against the servo horn lets the joint carry load through friction across the whole mating face, taking stress off the screw holes themselves rather than relying on the screws in shear alone.
- **Center hole → designed into the print.** Modeling the hole into the part kept the surrounding material continuous and the plate's structural integrity intact.
**Result:** these changes fixed the joint. The reprinted link has passed several further 1000 g tests without deformation.
 
---
 
## Failure #2: Elbow–Wrist Forearm Truss
 
<!-- MEDIA: photo of the twisted/deformed truss -->
Twisted elbow–wrist forearm truss
*The single-crossmember truss after it twisted under an off-axis load.*
 
This failure appeared during a demonstration of the rover lifting 1000 g. Mid-lift, the elbow–wrist link twisted along its length and deformed, and the arm failed.
 
**Root cause:**
 
I had designed the elbow–wrist link to be highly weight-optimized — strong where it needed to be, light everywhere else. Working from that mindset, I gave the top and bottom faces of the truss only a single crossmember each, because I expected the link to carry load only vertically, down the side faces. That reasoning held for a purely vertical load. But when the rover lifts a payload that isn't perfectly balanced, or when the arm accelerates in yaw, the load comes off the vertical axis and tries to twist the link along its length. With only one crossmember per face, the top and bottom behaved as an **open section**, which has very little torsional stiffness — so under that off-axis load, the truss twisted rather than holding its shape.
 
**Fix:**
 
<!-- MEDIA: render or photo of the two-crossmember redesign -->
Redesigned two-crossmember truss
*The redesign — a second crossmember on each face closes the section toward a box.*
 
I redesigned the truss with the same weight-optimization mindset but a corrected understanding of how it would actually be loaded. The change was to run **two crossmembers per face instead of one**. Tying the top and bottom faces together this way closes the section further — better approximating a true closed section, which resists torsion far better than an open one — while keeping the lightweight advantage of a truss over a solid beam. The realization behind the fix wasn't "add more material"; it was that I had modeled only the in-plane bending load and missed the torsional load path entirely.
 
**Result:** the redesigned truss has passed every 1000 g test since, and it holds its shape far better when the arm is loaded during dynamic movement.
 
---
 
## Takeaway
 
Both failures came from deliberately testing past the design requirement, which is what that testing is for — it found the real limits of the build. The shoulder joint failed because the as-built part drifted from its design under the pressure of rapid iteration; the fix was discipline in fabrication. The forearm truss failed because the design itself was built on an incomplete load model; the fix was a better understanding of the loads. Together they moved the arm from meeting its 0.5 kg target to holding 1000 g repeatably.

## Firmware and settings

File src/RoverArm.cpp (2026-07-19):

#include <Arduino.h>
#include <WiFi.h>
#include <WebServer.h>
#include <SCServo.h>

//Motor A pins
#define PWMA 25
#define AIN1 21
#define AIN2 17

//Motor B pins
#define PWMB 26
#define BIN1 22
#define BIN2 23

#define SERVO_TX 19
#define SERVO_RX 18

#define ID_SHOULDER_PITCH 2
#define ID_SHOULDER_YAW 1
#define ID_ELBOW 3
#define ID_WRIST 4

//--------Jog control------------
#define JOG_STEP 25 //position units added/removed per nudge
#define JOG_SPEED 800 //speed at which the jog moves


//Wifi Access point credentials
const char* apSSID = "RoverArm";
const char* apPassword = "rover1234";

WebServer server(80);
SMS_STS servos;

int jointPos[5];
int jointCenter [5];
int jointMin[5];
int jointMax[5];


//==================================
//Motor Control
//==================================
void setMotorA(int speed) {
  //speed: -255 (full reverse) to 255 (full forward)
  if (speed > 0) {
    digitalWrite(AIN1, HIGH);
    digitalWrite(AIN2, LOW);
  }else if (speed < 0) {
    digitalWrite(AIN1, LOW);
    digitalWrite(AIN2, HIGH);
  }else {
    digitalWrite(AIN1, LOW);
    digitalWrite(AIN2, LOW);
  }
  analogWrite(PWMA, abs(speed));  //abs() strips the negative
}

void setMotorB(int speed) {
  if (speed > 0) {
    digitalWrite(BIN1, HIGH);
    digitalWrite(BIN2, LOW);
  }else if (speed < 0) {
    digitalWrite(BIN1, LOW);
    digitalWrite(BIN2, HIGH);
  }else {
    digitalWrite(BIN1, LOW);
    digitalWrite(BIN2, LOW);
  }
  analogWrite(PWMB, abs(speed));
}
//This is to prevent the ESP Board browning out from high current draw from the motors, which causes the WiFi to go out
void rampMotors(int targetA, int targetB) {
  int currentA = 0;
  int currentB = 0;
  while (currentA != targetA || currentB != targetB) {
    if (currentA < targetA) currentA = min(currentA + 15, targetA);
    if (currentA > targetA) currentA = max(currentA - 15, targetA);
    if (currentB < targetB) currentB = min(currentB + 15, targetB);
    if (currentB > targetB) currentB = max(currentB - 15, targetB);
    setMotorA(currentA);
    setMotorB(currentB);
    delay(10);
  }
}
//==================================
//Sevo Control
//Feetech Position Units: 0-4095 = 0-360 degrees (~ 11.375 steps/degree)
//speed units: 0-32767 (higher->faster, 1500 is safe moderate)
//==================================
void moveServo(byte id, int pos, int spd) {
  servos.WritePosEx(id, pos, spd, 50);
  //end # = acceleration
}

void centerServo(byte id) {
  jointPos[id] = jointCenter[id];
  moveServo(id, jointCenter[id], 1500);
}

//nudges a joint one JOG_STEP further in the given direction
//constrained by position max/min
//-1 = up/left
//+1 = down/right
void nudgeJoint(byte id, int direction) {
  int newPos = jointPos[id] +(direction*JOG_STEP);
  newPos = constrain(newPos, jointMin[id], jointMax[id]);
  jointPos[id]=newPos;
  moveServo(id, newPos, JOG_SPEED);
}

const char* htmlPage = R"HTMLEND(
<!DOCTYPE html>
<html>
<head>
  <title>Rover Control</title>
  <meta name="viewport" content="width=device-width, initial-scale=1">
  <style>
    body {
      text-align: center;
      font-family: sans-serif;
      max-width: 400px;
      margin: auto;
      padding: 10px;
    }
    h2 { margin: 10px 0 5px 0; }
    hr { margin: 15px 0; }
    .btn {
      font-size: 18px;
      padding: 14px;
      margin: 4px;
      width: 100px;
      border: none;
      border-radius: 8px;
      background: #007AFF;
      color: white;
      cursor: pointer;
      user-select: none;
      -webkit-user-select: none;
      touch-action: manipulation;
    }
    .btn:active { background: #005BBB; }
    .stop { background: #FF3B30; width: 220px; }
    .stop:active { background: #CC2A22; }
    #status {
      font-size: 13px;
      color: gray;
      margin-top: 8px;
      height: 18px;
    }
  </style>
</head>
<body>
 
  <h1>Rover Control</h1>
  <div id="status">Ready</div>
 
  <h2>Drive</h2>
  <p><button class="btn" onclick="cmd('/forward')">Forward</button></p>
  <p>
    <button class="btn" onclick="cmd('/left')">Left</button>
    <button class="btn" onclick="cmd('/right')">Right</button>
  </p>
  <p><button class="btn" onclick="cmd('/backward')">Backward</button></p>
  <p><button class="btn stop" onclick="cmd('/stop')">STOP</button></p>
 
  <hr>
  <h2>Arm</h2>
  <p><button class="btn" onclick="cmd('/arm/center')">Center All</button></p>
 
  <h2>Shoulder Pitch</h2>
  <p>
    <button class="btn"
      onmousedown="startJog('/servo/shoulder_pitch/nudge_up', event)"
      onmouseup="stopJog()" onmouseleave="stopJog()"
      ontouchstart="startJog('/servo/shoulder_pitch/nudge_up', event)"
      ontouchend="stopJog()" ontouchcancel="stopJog()">Up</button>
    <button class="btn" onclick="cmd('/servo/shoulder_pitch/center')">Center</button>
    <button class="btn"
      onmousedown="startJog('/servo/shoulder_pitch/nudge_down', event)"
      onmouseup="stopJog()" onmouseleave="stopJog()"
      ontouchstart="startJog('/servo/shoulder_pitch/nudge_down', event)"
      ontouchend="stopJog()" ontouchcancel="stopJog()">Down</button>
  </p>
 
  <h2>Shoulder Yaw</h2>
  <p>
    <button class="btn"
      onmousedown="startJog('/servo/shoulder_yaw/nudge_left', event)"
      onmouseup="stopJog()" onmouseleave="stopJog()"
      ontouchstart="startJog('/servo/shoulder_yaw/nudge_left', event)"
      ontouchend="stopJog()" ontouchcancel="stopJog()">Left</button>
    <button class="btn" onclick="cmd('/servo/shoulder_yaw/center')">Center</button>
    <button class="btn"
      onmousedown="startJog('/servo/shoulder_yaw/nudge_right', event)"
      onmouseup="stopJog()" onmouseleave="stopJog()"
      ontouchstart="startJog('/servo/shoulder_yaw/nudge_right', event)"
      ontouchend="stopJog()" ontouchcancel="stopJog()">Right</button>
  </p>
 
  <h2>Elbow</h2>
  <p>
    <button class="btn"
      onmousedown="startJog('/servo/elbow/nudge_up', event)"
      onmouseup="stopJog()" onmouseleave="stopJog()"
      ontouchstart="startJog('/servo/elbow/nudge_up', event)"
      ontouchend="stopJog()" ontouchcancel="stopJog()">Up</button>
    <button class="btn" onclick="cmd('/servo/elbow/center')">Center</button>
    <button class="btn"
      onmousedown="startJog('/servo/elbow/nudge_down', event)"
      onmouseup="stopJog()" onmouseleave="stopJog()"
      ontouchstart="startJog('/servo/elbow/nudge_down', event)"
      ontouchend="stopJog()" ontouchcancel="stopJog()">Down</button>
  </p>
 
  <h2>Wrist</h2>
  <p>
    <button class="btn"
      onmousedown="startJog('/servo/wrist/nudge_up', event)"
      onmouseup="stopJog()" onmouseleave="stopJog()"
      ontouchstart="startJog('/servo/wrist/nudge_up', event)"
      ontouchend="stopJog()" ontouchcancel="stopJog()">Up</button>
    <button class="btn" onclick="cmd('/servo/wrist/center')">Center</button>
    <button class="btn"
      onmousedown="startJog('/servo/wrist/nudge_down', event)"
      onmouseup="stopJog()" onmouseleave="stopJog()"
      ontouchstart="startJog('/servo/wrist/nudge_down', event)"
      ontouchend="stopJog()" ontouchcancel="stopJog()">Down</button>
  </p>
 
  <script>
    function cmd(route) {
      var s = document.getElementById("status");
      s.textContent = "Sending...";
      var xhr = new XMLHttpRequest();
      xhr.open("GET", route, true);
      xhr.onload = function() {
        if (xhr.status === 200) {
          s.textContent = "OK";
        } else {
          s.textContent = "Error " + xhr.status;
        }
      };
      xhr.onerror = function() {
        s.textContent = "No response";
      };
      xhr.send();
    }
 
    // ── Hold-to-jog control ─────────────────────────────────
    // While a jog button is held, fire cmd(route) repeatedly.
    // On release, stop firing -- the servo simply stays at its
    // last commanded position (no separate "stop" needed).
    let jogInterval = null;
 
    function startJog(route, evt) {
      if (evt) evt.preventDefault(); // stop touch from also firing a synthetic mousedown
      if (jogInterval) return;       // already jogging, ignore repeat triggers
      cmd(route);                    // immediate first move so it feels responsive
      jogInterval = setInterval(function() { cmd(route); }, 20);
    }
 
    function stopJog() {
      if (jogInterval) {
        clearInterval(jogInterval);
        jogInterval = null;
      }
    }
  </script>
 
</body>
</html>
)HTMLEND";

void handleRoot() {
  server.send(200, "text/html", htmlPage);
}

void handleForward()  { rampMotors(150, 150);    server.send(200, "text/plain", "OK"); }
void handleBackward() { rampMotors(-150, -150);  server.send(200, "text/plain", "OK"); }
void handleLeft()     { rampMotors(-150, 150);   server.send(200, "text/plain", "OK"); }
void handleRight()    { rampMotors(150, -150);   server.send(200, "text/plain", "OK"); }
//void handleStop()     { rampMotors(0, 0);        server.send(200, "text/plain", "OK"); }
void handleStop() {
  setMotorA(0);
  setMotorB(0);
  server.send(200, "text/html", htmlPage);
}
void handleArmCenter() {
  centerServo(ID_SHOULDER_PITCH);
  centerServo(ID_SHOULDER_YAW);
  centerServo(ID_ELBOW);
  centerServo(ID_WRIST);
  server.send(200, "text/plain", "OK");
}

// ── Shoulder pitch ─────────────────────────────────────────────
void handleShoulderPitchNudgeUp()     { nudgeJoint(ID_SHOULDER_PITCH, +1); server.send(200, "text/plain", "OK"); }
void handleShoulderPitchNudgeDown()   { nudgeJoint(ID_SHOULDER_PITCH, -1); server.send(200, "text/plain", "OK"); }
void handleShoulderPitchCenter()   { centerServo(ID_SHOULDER_PITCH); server.send(200, "text/plain", "OK"); }

// ── Shoulder yaw ───────────────────────────────────────────────
void handleShoulderYawNudgeLeft()     { nudgeJoint(ID_SHOULDER_YAW, +1); server.send(200, "text/plain", "OK"); }
void handleShoulderYawCenter()   { centerServo(ID_SHOULDER_YAW); server.send(200, "text/plain", "OK"); }
void handleShoulderYawNudgeRight()    { nudgeJoint(ID_SHOULDER_YAW, -1); server.send(200, "text/plain", "OK"); }

// ── Elbow ──────────────────────────────────────────────────────
void handleElbowNudgeUp()     { nudgeJoint(ID_ELBOW, +1); server.send(200, "text/plain", "OK"); }
void handleElbowCenter() { centerServo(ID_ELBOW); server.send(200, "text/plain", "OK"); }
void handleElbowNudgeDown()   { nudgeJoint(ID_ELBOW, -1); server.send(200, "text/plain", "OK"); }

// ── Wrist ──────────────────────────────────────────────────────
void handleWristNudgeUp()     { nudgeJoint(ID_WRIST, +1); server.send(200, "text/plain", "OK"); }
void handleWristCenter() { centerServo(ID_WRIST); server.send(200, "text/plain", "OK"); }
void handleWristNudgeDown()   { nudgeJoint(ID_WRIST, -1); server.send(200, "text/plain", "OK"); }


//==================================
//Setup & Loop
//==================================


void setup() {
  // put your setup code here, to run once:
  Serial.begin(115200);
    Serial.println("Build: " __DATE__ " " __TIME__);


  pinMode(AIN1, OUTPUT);
  pinMode(AIN2, OUTPUT);
  pinMode(PWMA, OUTPUT);
  pinMode(BIN1, OUTPUT);
  pinMode(BIN2, OUTPUT);
  pinMode(PWMB, OUTPUT);

  Serial1.begin(1000000, SERIAL_8N1, SERVO_RX, SERVO_TX);
  servos.pSerial = &Serial1;
  delay(100);

//Servo Rotation limits and centers
jointCenter[ID_SHOULDER_PITCH] = 2688;
jointMin[ID_SHOULDER_PITCH] = 2200;
jointMax[ID_SHOULDER_PITCH] = 3366;
jointPos[ID_SHOULDER_PITCH] = jointCenter[ID_SHOULDER_PITCH];

jointCenter[ID_SHOULDER_YAW] = 2815;
jointMin[ID_SHOULDER_YAW] = 0; //consider removing min/max for yaw
jointMax[ID_SHOULDER_YAW] = 4095;
jointPos[ID_SHOULDER_YAW] = jointCenter[ID_SHOULDER_YAW];

jointCenter[ID_ELBOW] = 1693;
jointMin[ID_ELBOW] = 880;
jointMax[ID_ELBOW] = 3680;
jointPos[ID_ELBOW] = jointCenter[ID_ELBOW];

jointCenter[ID_WRIST] = 2048;
jointMin[ID_WRIST] = 0;
jointMax[ID_WRIST] = 4095;
jointPos[ID_WRIST] = jointCenter[ID_WRIST];

  WiFi.softAP(apSSID, apPassword); //turn ESP into its own WiFi
  IPAddress ip = WiFi.softAPIP();
  Serial.print("Acess Point started. Connect to WiFi: ");
  Serial.println(apSSID);
  Serial.print("Then go to: http://");
  Serial.println(ip);

  server.on("/", handleRoot);
  server.on("/forward", handleForward);
  server.on("/backward", handleBackward);
  server.on("/stop", handleStop);
  server.on("/left",  handleLeft);
  server.on("/right", handleRight);
  
  // Arm routes
  server.on("/arm/center",              handleArmCenter);
  server.on("/servo/shoulder_pitch/nudge_up",     handleShoulderPitchNudgeUp);
  server.on("/servo/shoulder_pitch/center", handleShoulderPitchCenter);
  server.on("/servo/shoulder_pitch/nudge_down",   handleShoulderPitchNudgeDown);
  server.on("/servo/shoulder_yaw/nudge_left",     handleShoulderYawNudgeLeft);
  server.on("/servo/shoulder_yaw/center",   handleShoulderYawCenter);
  server.on("/servo/shoulder_yaw/nudge_right",    handleShoulderYawNudgeRight);
  server.on("/servo/elbow/nudge_up",     handleElbowNudgeUp);
  server.on("/servo/elbow/center", handleElbowCenter);
  server.on("/servo/elbow/nudge_down",   handleElbowNudgeDown);
  server.on("/servo/wrist/nudge_up",     handleWristNudgeUp);
  server.on("/servo/wrist/center", handleWristCenter);
  server.on("/servo/wrist/nudge_down",   handleWristNudgeDown);

  server.begin();
  Serial.println("Server started - navigate to IP Address");

}

void loop() {
  server.handleClient(); //check for incoming button requests}
}

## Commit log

2026-06-19 prints a increasing number to serial port while printing it doubled as well
2026-06-20 Added if/else function that prints a warning to serial monitor if messagecount >= 5
2026-06-20 Broken-supposed to require input when rotation is >10, but the input is failing due to the delay command
    [main.cpp]
2026-06-20 Attempted fix to serial monitor inut problem using millis() but failed
    [main.cpp]
2026-06-20 Working code for wireless connection via WiFi hosted by ESP32 and IP Address website for controls
2026-07-14 the working code for the rover and arm. Uses set positions to move servos so is ineffectie
2026-07-21 Miscellaneous changes to overview and key engineering decisions, and added a gif of the arm lifting 800g
2026-07-21 added cad folder with some finished components in stl and step
    [drive-wheel.step, drive-wheel.stl, non-drive-wheel.step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]
2026-07-21 added two more cad files, antenna-structure and servo-bracket
    [antenna-structure.step, antenna-structure.stl, servo-bracket.step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]
2026-07-22 added cad files, remaining files need to be printed and tested to finalize
    [USB-holder.step, USB-holder.stl, fork-end-effector.step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]
2026-07-22 updated README misspellings, key engineering decisions, and cad section
2026-07-25 Added torquecalculations.md template from Claude and began adding the numbers from my calculations
2026-07-26 Updated torquecalculations.md to include Inertial calculations on the shoulder joint
2026-07-28 Explained shoulder servo selection despite 5.5% margin below safety factor
2026-07-29 Added servo fault documentation
    Updated the document to clarify the diagnosis process for servo faults, emphasizing the importance of systematic elimination of potential issues before concluding a hardware fault.
2026-07-30 Added more STEP files
    [USB-holder.step, chassis.step, counterweight-clamp.step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]
2026-07-30 Added more STL files
    [chassis.stl, counterweight-clamp.stl, counterweight-holder.stl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]
2026-07-30 Added updated shoulder-elbow-servo-link STEP file
    [shoulder-elbow-servo-link.step]
2026-07-30 Added updated shoulder-elbow-servo-link STL file
    [shoulder-elbow-servo-link.stl]
2026-07-30 Added updated elbow-wrist-link STEP file
    [elbow-wrist-link.step]
2026-07-30 Added updated elbow-wrist-link STL file
    [elbow-wrist-link.stl]
2026-07-30 Add wiring diagram and control architecture documentation
    Document the migration from Arduino Uno to Waveshare ESP32, detailing the reasons for the architecture change and providing wiring diagrams.
2026-07-30 Added wiring diagram photos
2026-07-30 moved wiringdiagrams.md out of cad/stl
2026-07-30 Revise wiring diagrams and architecture explanations
    Clarified reasons for architecture change from Arduino Uno to Waveshare ESP32. Updated diagrams and descriptions for original and current architectures.
2026-07-30 moved wiringdiagrams.md into /docs
2026-07-30 Fix image paths in wiringdiagrams.md
2026-07-30 Update README with wiring diagrams reference
    Added a reference to wiring diagrams for clarity on internal wiring reduction.
2026-07-30 Fix link to wiringdiagrams.md in README
    Updated the link to the wiring diagrams in the README.
2026-07-30 Deleted duplicate wiringdiagrams.md file
2026-07-30 Add images and descriptions for CAD render side-by-side views
2026-07-30 Added CAD renders to go alongside rover pictures
2026-07-30 Added servo diagnosis tree to /media
2026-07-30 Added servo diagnosis tree image to the servo fault isolation document
2026-07-31 Revise README key engineering decisions on servo selection and base stability under payload
2026-07-31 Edited counterweight section in torquecalculations.md
2026-07-31 Fixed image rendering problem in servofaultsiolation.md
2026-07-31 Added BOM to /docs
    [BOM.xlsx]
2026-07-31 Updated BOM section in README
2026-07-31 Clarify servo fault isolation process and terminology
    Updated terminology for clarity and improved the explanation of the diagnosis process, including details about testing and eliminating potential issues.
2026-07-31 Fixed typos in Servo Fault Isolation
2026-07-31 Fixed mathematical notation and clarified text in torquecalculations.md
2026-07-31 Fixed unit mismatch in torquecalculations.md
2026-08-03 Added structural failure analysis document
    Documented structural failures encountered during rover testing at 1000 g payload, detailing root causes and fixes for both the shoulder-elbow joint and elbow-wrist forearm truss.
2026-08-04 Added redesigned elbow-wrist truss photos, renders, and CAD files
    [elbow-wrist-link.step, elbow-wrist-link.stl]
2026-08-05 Clarified terminology in torquecalculations.md and added new mobility test video
2026-08-05 Updated torquecalculations.md with accurate safety factor values for the shoulder servo
